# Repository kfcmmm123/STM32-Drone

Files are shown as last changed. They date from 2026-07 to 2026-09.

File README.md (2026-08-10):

# STM32 Quadcopter

A custom **STM32F103C8T6** + **FreeRTOS** quadcopter system with separate flight-controller (FC) and radio-controller (RC) boards.

The project focuses on real-time embedded firmware, attitude estimation, closed-loop flight control, wireless communication, and flight-safety logic.

## Features 

- FreeRTOS multi-task firmware architecture
- MPU6050 IMU acquisition and filtering
- Quaternion-based attitude estimation
- Cascaded angle–angular velocity PID control
- Altitude sensing and altitude-hold mode
- Si24R1 2.4 GHz wireless communication
- PWM control for four coreless motors
- Flight-state management and Safe-Unlock logic
- Connection-loss detection and failsafe motor ramp-down
- OLED and LED status feedback
- Power-management logic

--- 

## System Architecture

### Flight Controller

- **MCU:** STM32F103C8T6 + FreeRTOS
- **IMU:** MPU6050 over I²C
- **Altitude Sensor:** VL53L1X ToF sensor over I²C
- **Motors:** 4× 8520 coreless motors with timer/PWM control
- **Wireless:** Si24R1 2.4 GHz transceiver over SPI
- **Power:** Battery power management with IP5305T
- **Indicators:** GPIO-controlled status LEDs
- **Debug:** SWD interface

### Radio Controller

- **MCU:** STM32F103C8T6 + FreeRTOS
- **Input:** Dual analog joysticks through ADC
- **Controls:** GPIO push buttons
- **Display:** OLED display
- **Wireless:** Si24R1 2.4 GHz transceiver over SPI
- **Power:** IP5305T power management

---

## Hardware Design

Both controller boards were designed and routed in **EasyEDA**, with consideration for:

- Ground planes and low-noise signal return paths
- Separation of motor power and sensitive digital/sensor signals
- Short SPI and I²C routing
- High-current motor routing
- Local decoupling and power regulation
- Peripheral and timer-aware STM32 pin assignment
- Mechanical clearance and component placement

### Flight Controller PCB

The FC integrates the STM32, IMU, range sensor, RF module, motor drivers, power circuitry, and debug interfaces onto a compact PCB.

<div className="grid grid-cols-2 gap-2 my-6">
  <div>
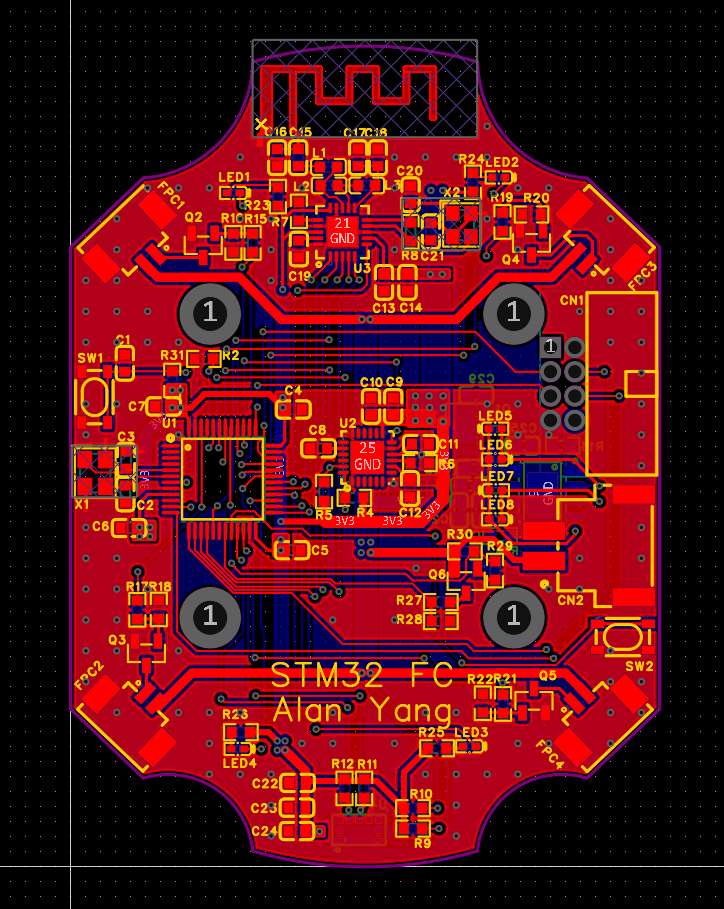
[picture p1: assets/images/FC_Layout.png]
FC Layout
    
    <p className="text-center text-sm">FC Layout</p>
  </div>
  <div>
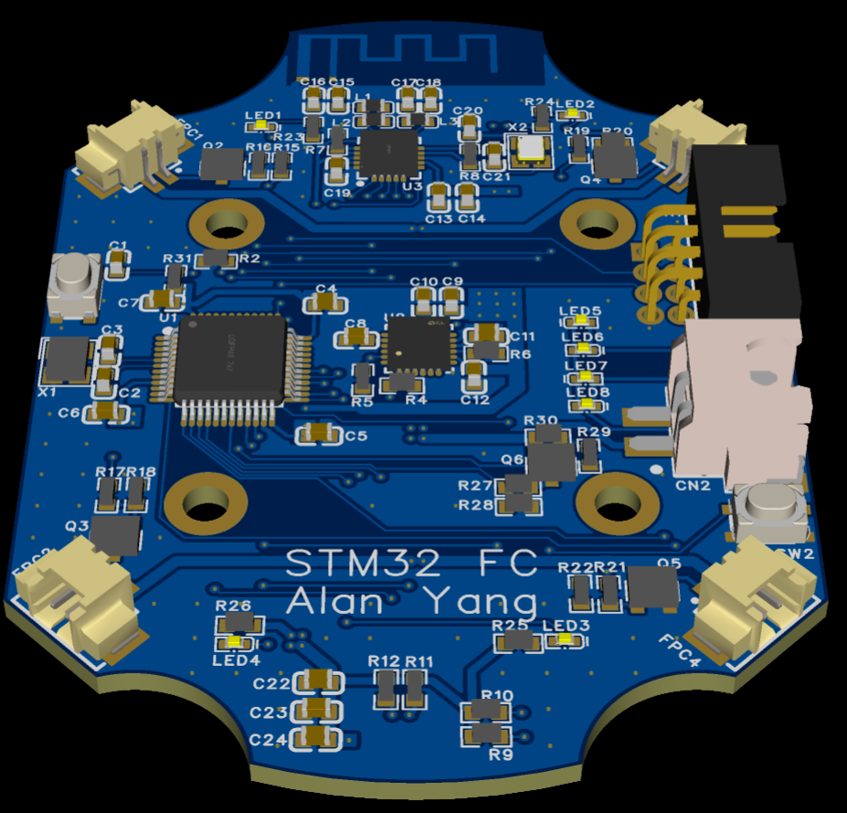
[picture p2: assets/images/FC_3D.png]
FC 3D Visualization
    
    <p className="text-center text-sm">FC 3D Visualization</p>
  </div>
</div>

### Radio Controller PCB

The RC integrates dual joysticks, control buttons, OLED feedback, RF communication, and portable power management into a handheld controller.

<div className="grid grid-cols-2 gap-2 my-6">
  <div>
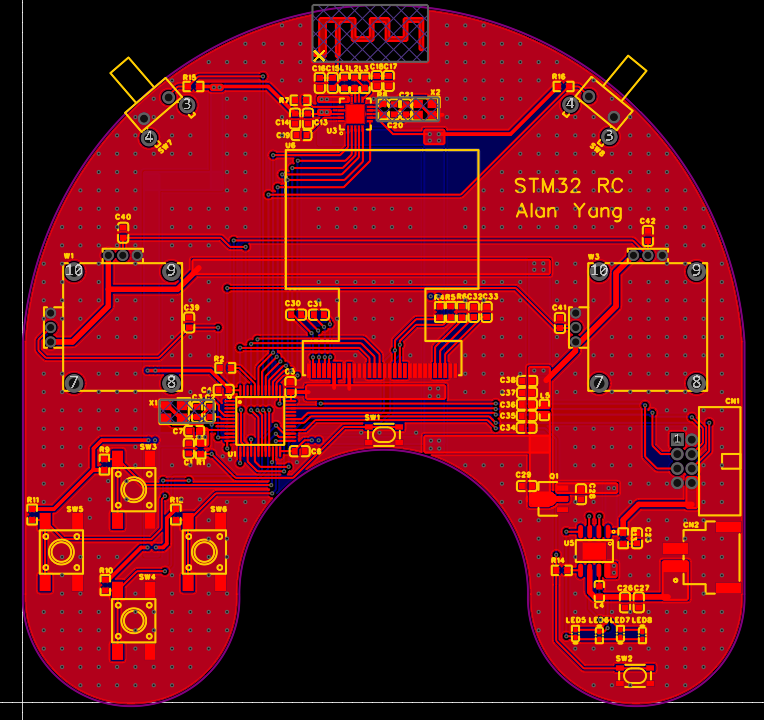
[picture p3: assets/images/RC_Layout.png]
RC Layout
    
    <p className="text-center text-sm">RC Layout</p>
  </div>
  <div>
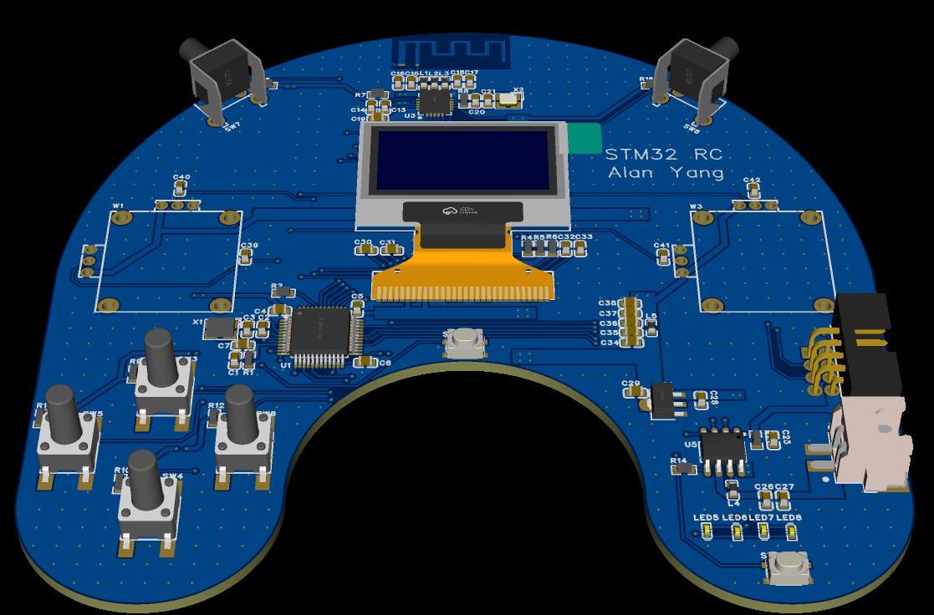
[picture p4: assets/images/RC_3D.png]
RC 3D Visualization
    
    <p className="text-center text-sm">RC 3D Visualization</p>
  </div>
</div>

### Assembled PCBs

<div className="grid grid-cols-2 gap-2 my-6">
  <div>
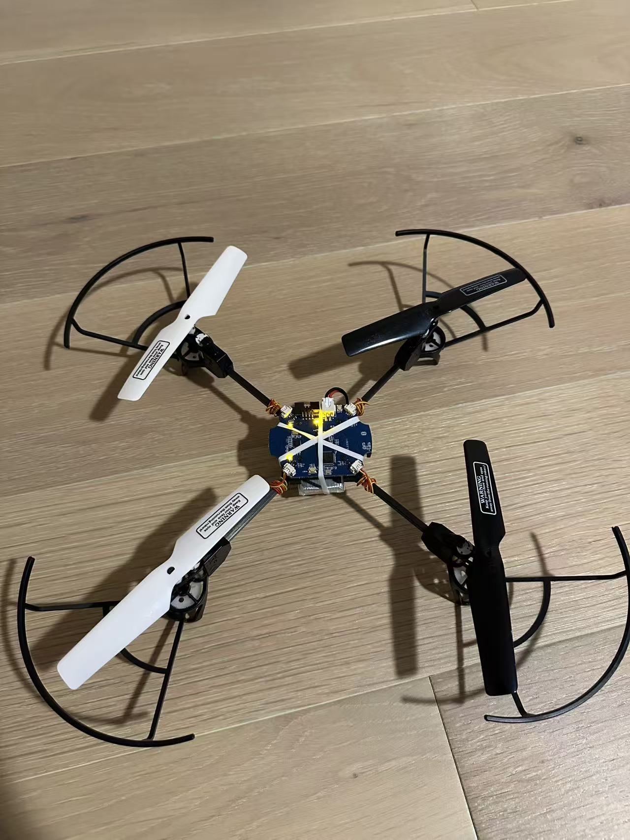
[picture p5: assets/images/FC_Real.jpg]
FC PCB
    
    <p className="text-center text-sm">FC PCB</p>
  </div>
  <div>
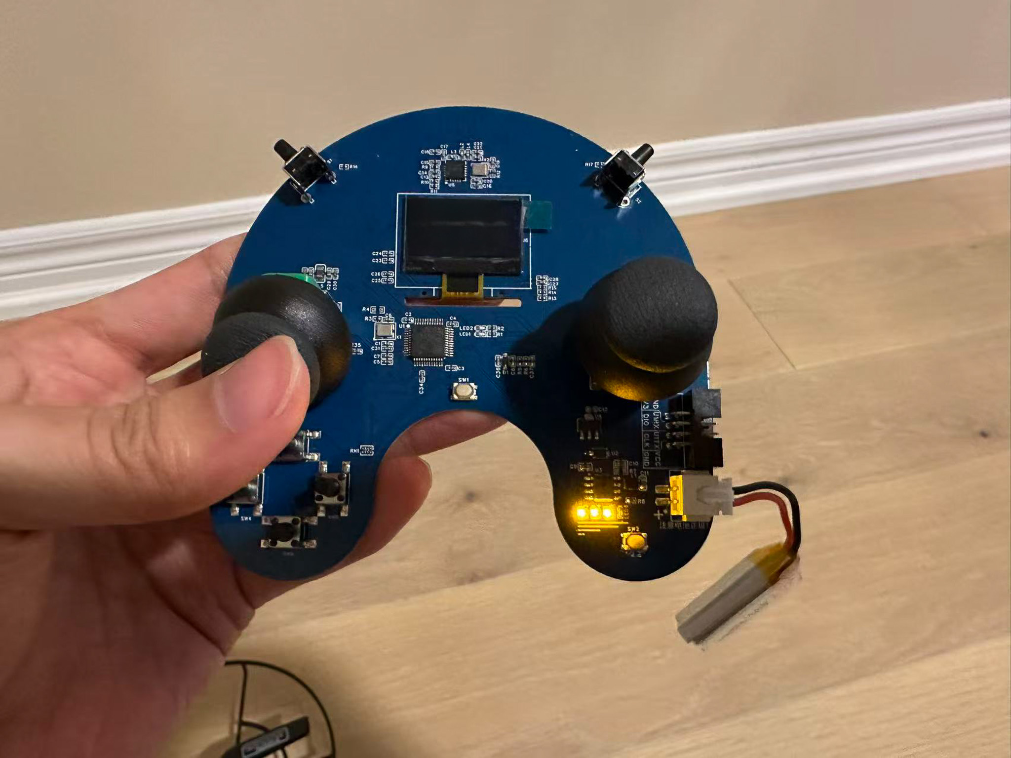
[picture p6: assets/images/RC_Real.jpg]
RC PCB
    
    <p className="text-center text-sm">RC PCB</p>
  </div>
</div>

---

## Firmware Development

The firmware is built on **FreeRTOS** with a layered architecture separating application, control algorithm, and hardware driver logic.

### Key Features

- FreeRTOS multi-task architecture
- Quaternion-based attitude estimation with sensor filtering
- Cascaded angle–angular velocity PID flight control
- Altitude-hold control using VL53L1X
- Custom Si24R1 2.4 GHz communication protocol
- Safe-Unlock, flight state machine, and Failsafe protection

### Flight Controller (FC)

- Reads and filters MPU6050 IMU data for real-time attitude estimation
- Runs cascaded PID control and mixes outputs across four motors
- Supports altitude hold and `IDLE`, `NORMAL`, `FIX_HEIGHT`, and `FAULT` states
- Handles wireless loss, Failsafe, Safe-Unlock, and shutdown behavior

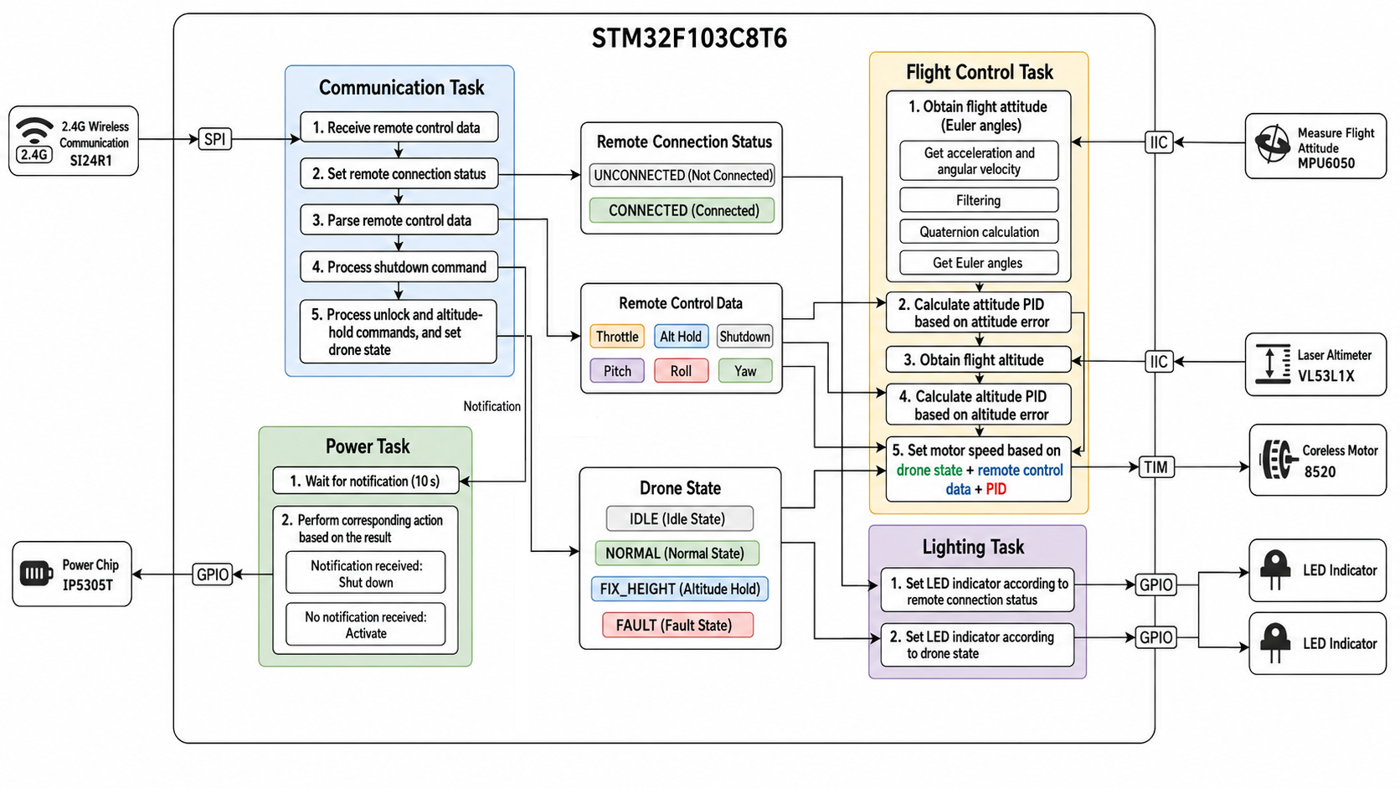
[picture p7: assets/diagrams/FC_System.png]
FC FW System


### Radio Controller (RC)

- Samples and calibrates dual analog joysticks through ADC
- Generates throttle, pitch, roll, yaw, altitude-hold, and system commands
- Packages and transmits validated control packets over Si24R1
- Manages OLED feedback, buttons, connection status, and power

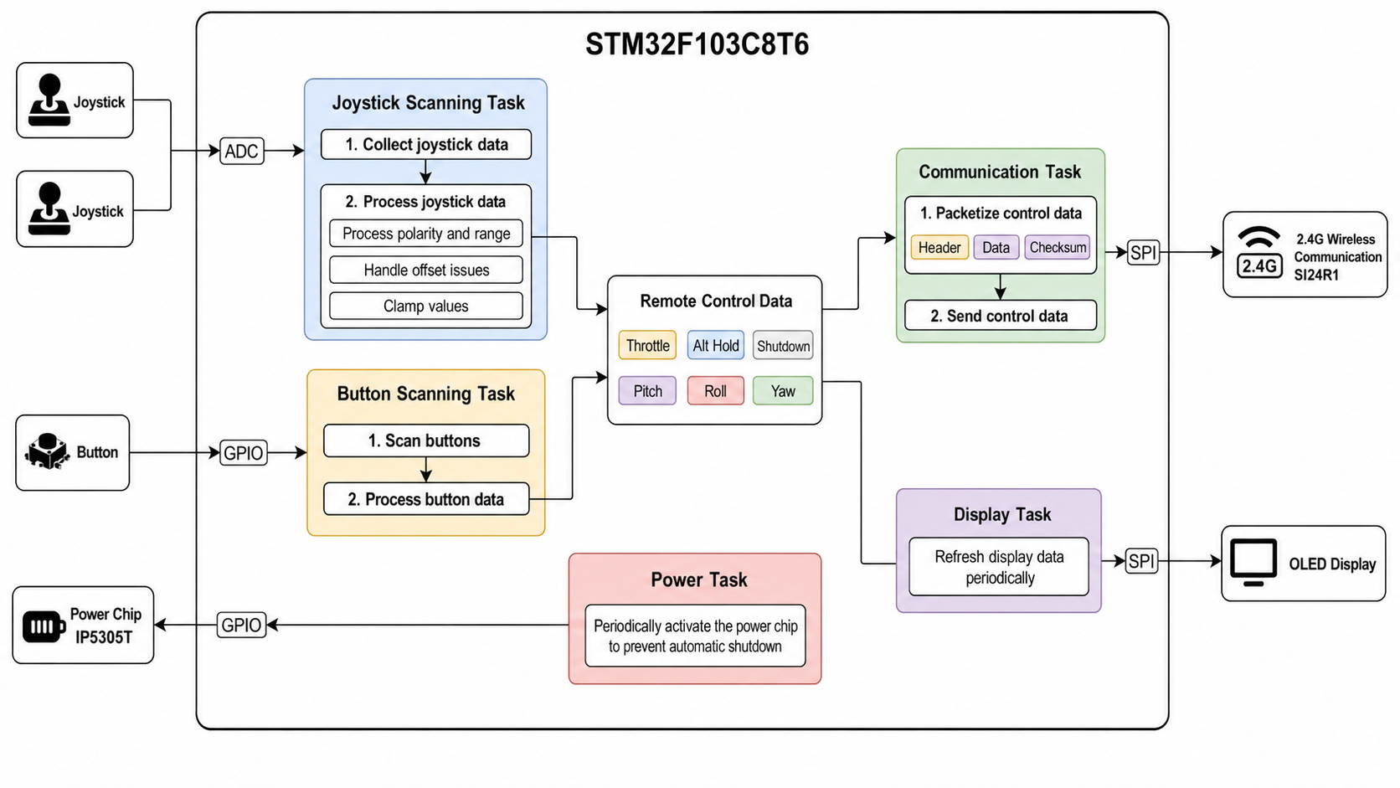
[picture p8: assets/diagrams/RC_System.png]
FC FW System


---

## Skills Demonstrated

- STM32 embedded C & FreeRTOS development
- Schematic design & PCB layout
- SPI, I²C, ADC, GPIO & PWM
- IMU filtering & quaternion attitude estimation
- Cascaded PID flight control
- Embedded state machines & Failsafe design
- Custom 2.4 GHz wireless communication
- Hardware/firmware system integration

This project demonstrates the complete embedded systems workflow: from PCB design and hardware integration to real-time firmware, wireless communication, sensor processing, and closed-loop flight control.

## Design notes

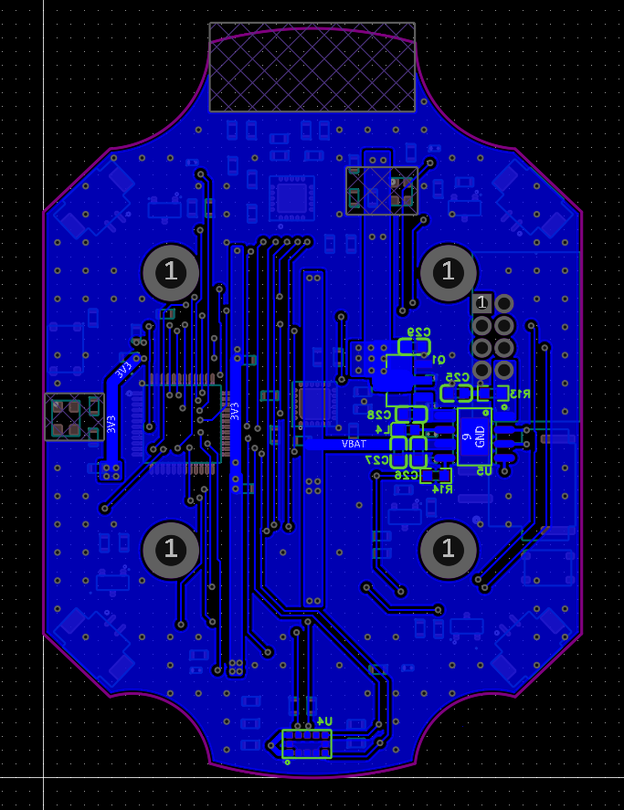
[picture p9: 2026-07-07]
assets/images/FC_Bot.png

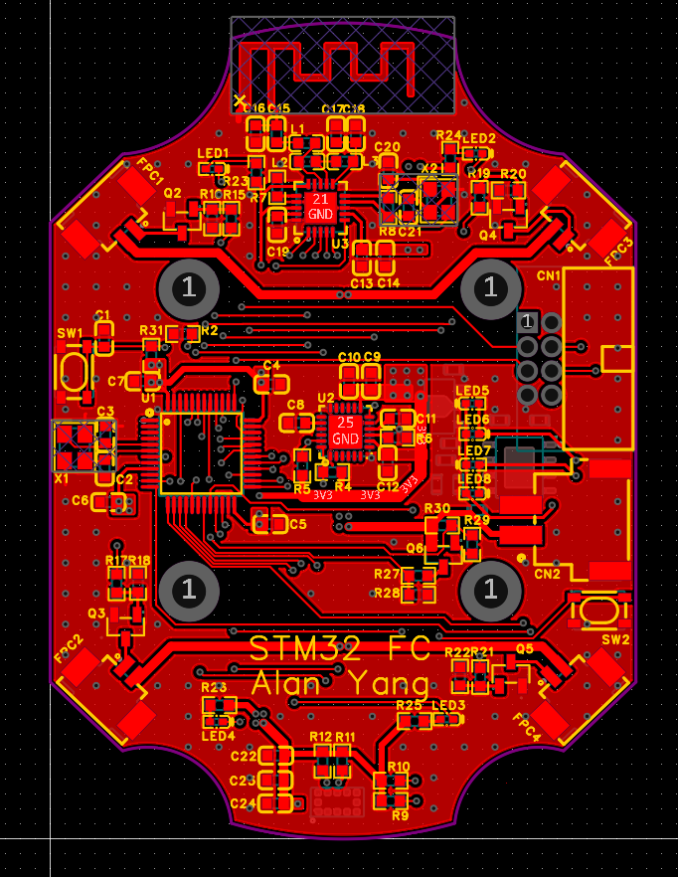
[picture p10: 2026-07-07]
assets/images/FC_Top.png

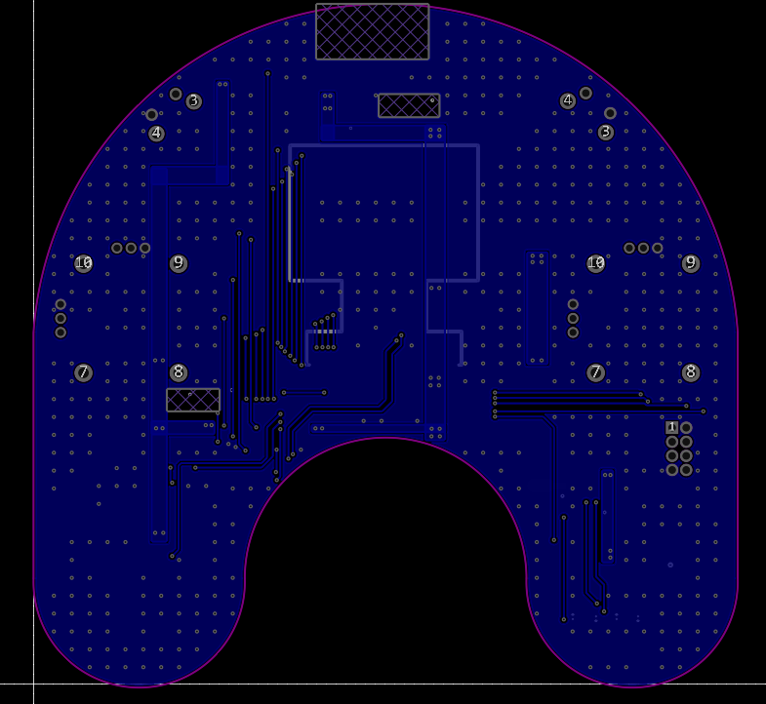
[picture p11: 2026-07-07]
assets/images/RC_Bot.png

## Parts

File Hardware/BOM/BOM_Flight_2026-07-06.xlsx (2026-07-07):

No. | Quantity | Comment | Designator | Footprint | Value | Manufacturer Part | Manufacturer | Supplier Part | Supplier
1 | 9 | 100nF | C1,C4,C5,C6,C7,C9,C11,C13,C22 | C0603 | 100nF
2 | 2 | 12pF | C2,C3 | C0603 | 12pF
3 | 2 | 10nF | C8,C12 | C0603 | 10nF
4 | 2 | 2.2nF | C10,C18 | C0603 | 2.2nF
5 | 5 | 10uF | C14,C26,C27,C28,C29 | C0603 | 10uF
6 | 1 | 1.5pF | C15 | C0603 | 1.5pF
7 | 2 | 1pF | C16,C24 | C0603 | 1pF
8 | 1 | 4.7pF | C17 | C0603 | 4.7pF
9 | 1 | 33nF | C19 | C0603 | 33nF
10 | 2 | 22pF | C20,C21 | C0603 | 22pF
11 | 1 | 4.7uF | C23 | C0603 | 4.7uF
12 | 1 | 2.2uF | C25 | C0603 | 2.2uF
13 | 1 | 3111-08RG0BK00T1 | CN1 | CONN-TH_3111-08RG0BK00T1 |  | 3111-08RG0BK00T1 | Wcon(维峰电子) | C720751 | LCSC
14 | 1 | ZX-XH2.54-2PWT | CN2 | CONN-SMD_2P-P2.54_MEGASTAR_ZX-XH2.54-2PWT |  | ZX-XH2.54-2PWT | Megastar(兆星) | C7429671 | LCSC
15 | 4 | 1.25-2PWB | FPC1,FPC2,FPC3,FPC4 | CONN-SMD_2P-P1.25_DEALON_1.25-2PWB |  | 1.25-2PWB | DEALON(德艺隆) | C2905009 | LCSC
16 | 1 | 3.9uH | L1 | L0603 | 3.9uH
17 | 1 | 8.2nH | L2 | L0603 | 8.2nH
18 | 1 | 2.7nH | L3 | L0603 | 2.7nH
19 | 1 | 1.5uH | L4 | L0603 | 1.5uH
20 | 8 | XL-1005UYC | LED1,LED2,LED3,LED4,LED5,LED6,LED7,LED8 | LED0402-FD_YELLOW |  | XL-1005UYC | XINGLIGHT(成兴光) | C25503856 | LCSC
21 | 1 | AMS1117-3.3V | Q1 | SOT-89-3_L4.5-W2.5-P1.50-LS4.2-BR |  | AMS1117-3.3V | MSKSEMI(美森科) | C5120796 | LCSC
22 | 4 | AO3400A | Q2,Q3,Q4,Q5 | SOT-23-3_L2.9-W1.3-P1.90-LS2.4-BR |  | AO3400A | UMW(友台半导体) | C347475 | LCSC
23 | 1 | SI2301A | Q6 | SOT-23-3_L2.9-W1.3-P1.90-LS2.4-BR |  | SI2301A | UMW(友台半导体) | C347482 | LCSC
24 | 16 | 10K | R2,R6,R9,R10,R11,R12,R14,R16,R18,R20,R22,R23,R24,R25,R26,R31 | R0603 | 10K
25 | 2 | 10KΩ | R4,R5 | R0603 | 10KΩ
26 | 1 | 22K | R7 | R0603 | 22K
27 | 1 | 1MΩ | R8 | R0603 | 1MΩ
28 | 1 | 1.5Ω | R13 | R0603 | 1.5Ω
29 | 5 | 1K | R15,R17,R19,R21,R29 | R0603 | 1K
30 | 3 | 100K | R27,R28,R30 | R0603 | 100K
31 | 2 | SKRPACE010 | SW1,SW2 | KEY-SMD_4P-L4.2-W3.2-P2.20-LS4.6 |  | SKRPACE010 | ALPSALPINE(阿尔卑斯阿尔派) | C139797 | LCSC
32 | 1 | STM32F103C8T6 | U1 | LQFP-48_L7.0-W7.0-P0.50-LS9.0-BL |  | STM32F103C8T6 | ST(意法半导体) | C8734 | LCSC
33 | 1 | MPU-6050 | U2 | QFN-24_L4.0-W4.0-P0.50-BL-EP2.7 |  | MPU-6050 | TDK InvenSense(应美盛) | C24112 | LCSC
34 | 1 | Si24R1 | U3 | QFN-20_L4.0-W4.0-P0.50-BL-EP |  | Si24R1 | 南京中科微 | C14436 | LCSC
35 | 1 | VL53L4CDV0DH/1 | U4 | LGA-12_L4.4-W2.4_VL53L0X |  | VL53L4CDV0DH/1 | ST(意法半导体) | C3178291 | LCSC
36 | 1 | TP4336 | U5 | ESOP-8_L4.9-W3.9-P1.27-LS6.0-BL-EP-1 |  | TP4336 | TPOWER(天源) | C29075510 | LCSC
37 | 1 | 8MHz | X1 | CRYSTAL-SMD_4P-L3.2-W2.5-BL | 8MHz | TAXM8M4RLBDDT2T | YJX(雅晶鑫) | C720915 | LCSC
38 | 1 | - | X2 | CRYSTAL-SMD_4P-L2.5-W2.0-BL-2 | - | SX25Y016000B91T | TKD(泰晶) | C271644 | LCSC

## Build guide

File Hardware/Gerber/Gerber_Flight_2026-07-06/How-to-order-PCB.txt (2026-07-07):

How to Order PCB

Please refer to:
https://prodocs.easyeda.com/en/pcb/order-order-pcb/index.html

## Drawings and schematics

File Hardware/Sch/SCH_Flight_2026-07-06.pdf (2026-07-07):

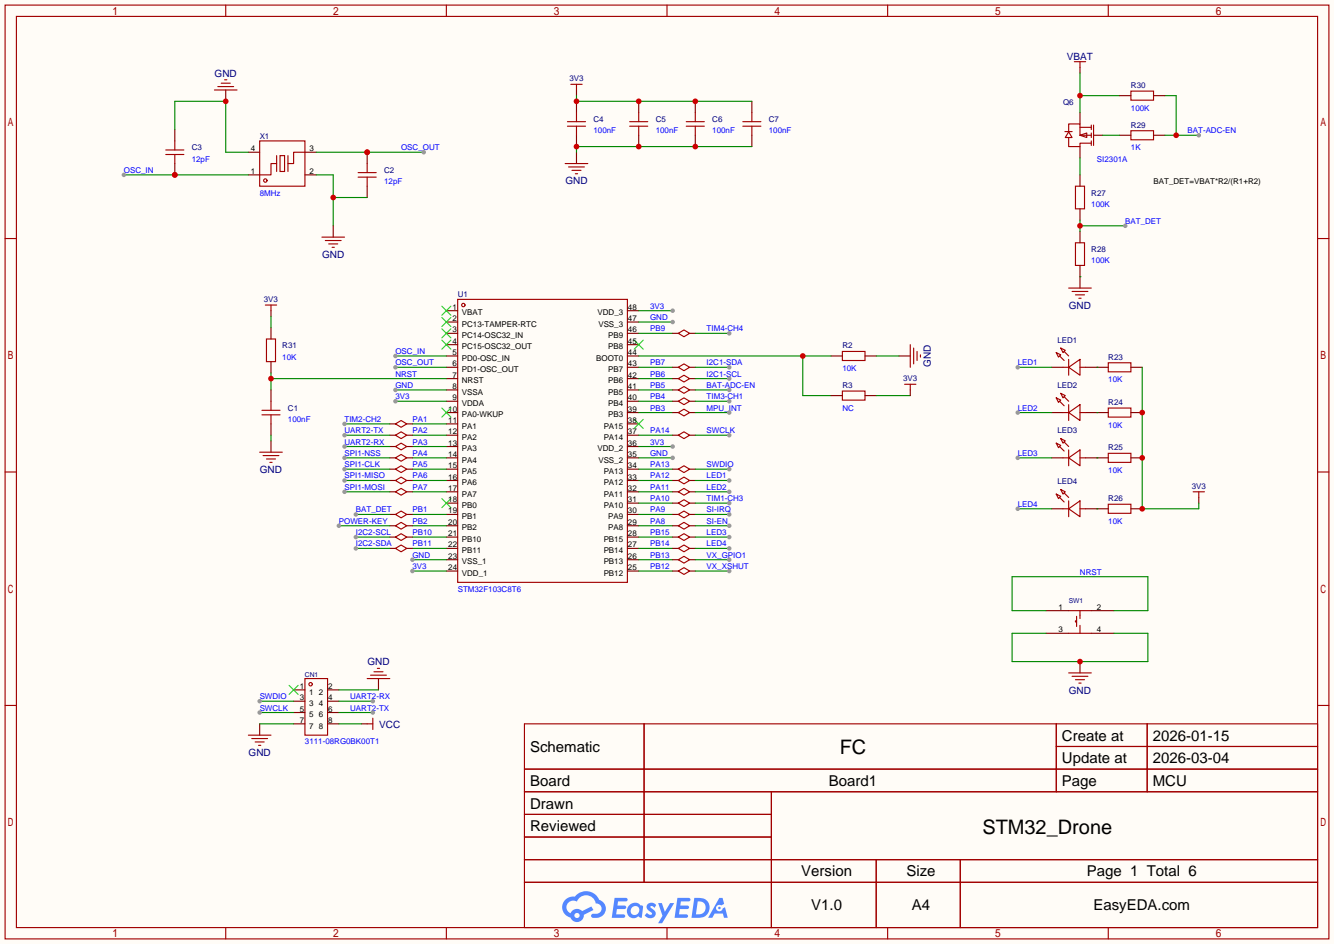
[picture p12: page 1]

Schematic | FC | Create at | 2026-01-15

Update at | 2026-03-04

Board | Board1 | Page | MCU
Drawn | | STM32_Drone
Reviewed

Version | Size | Page 1 Total 6
V1.0 | A4 | EasyEDA.com

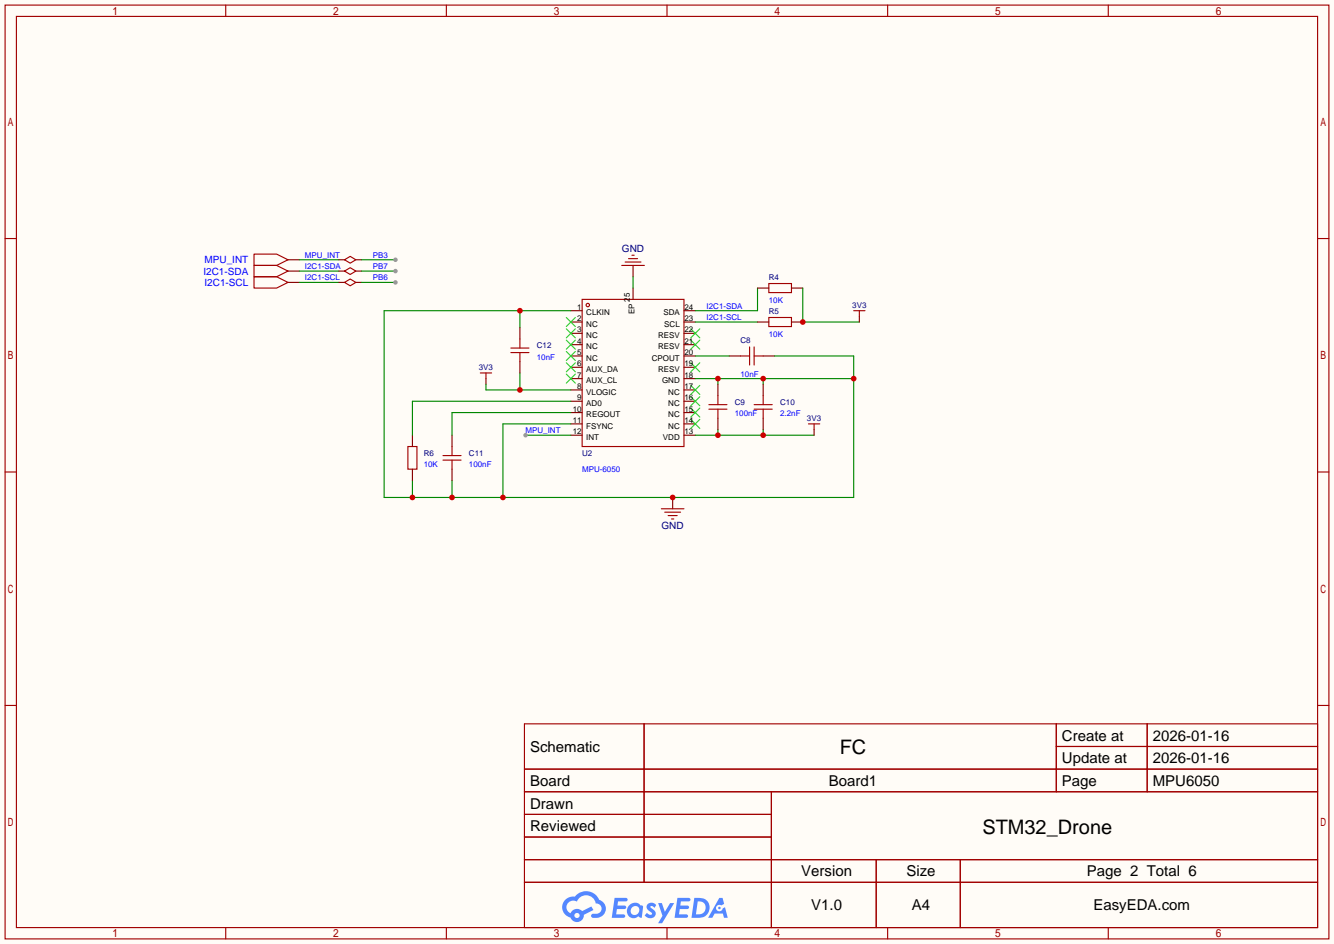
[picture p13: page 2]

Schematic | FC | Create at | 2026-01-16

Update at | 2026-01-16

Board | Board1 | Page | MPU6050
Drawn | | STM32_Drone
Reviewed

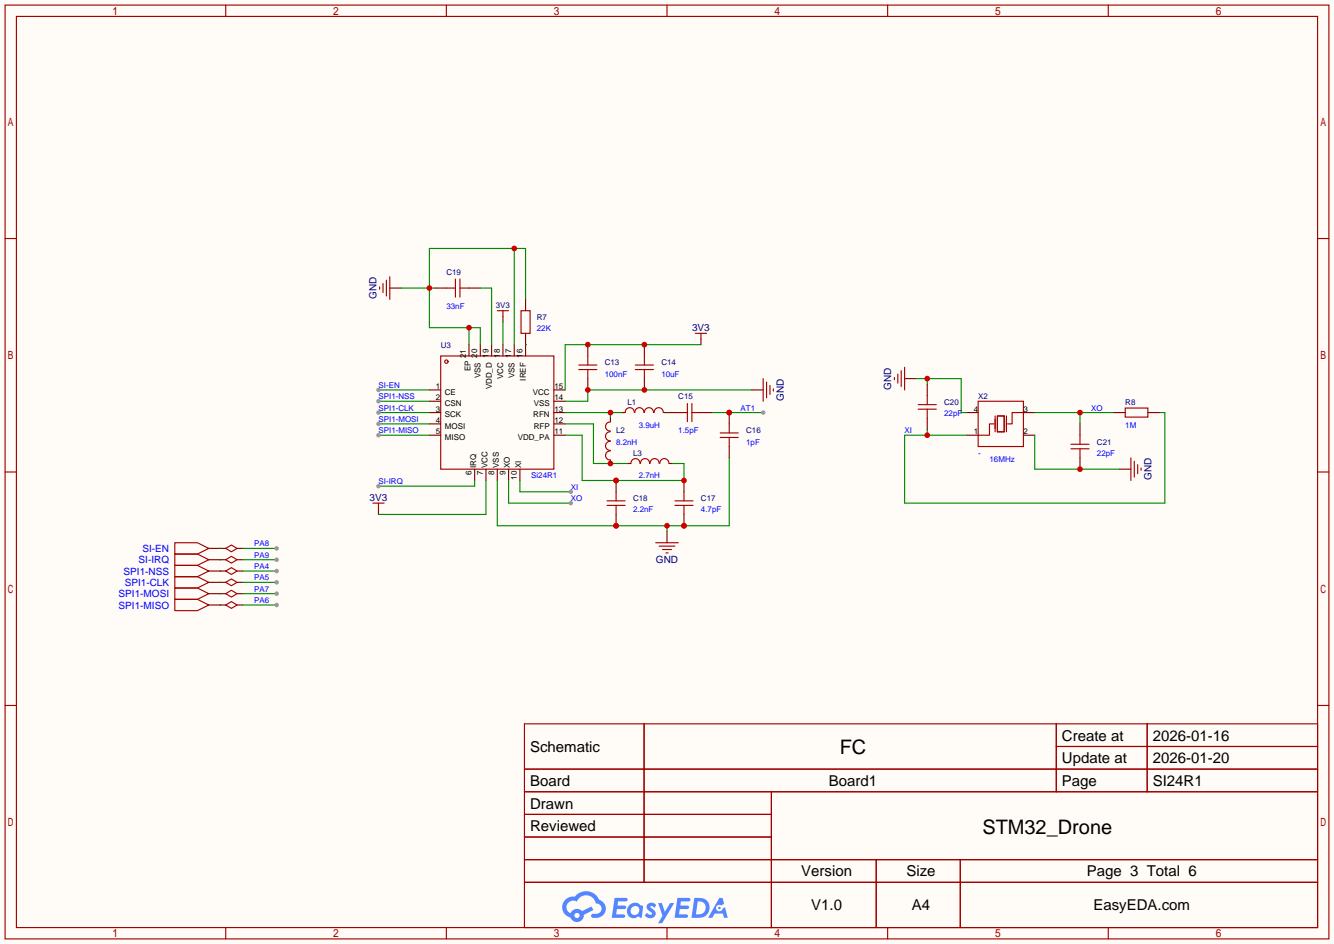
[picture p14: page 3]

Schematic | FC | Create at | 2026-01-16

Update at | 2026-01-20

Board | Board1 | Page | SI24R1
Drawn | | STM32_Drone
Reviewed

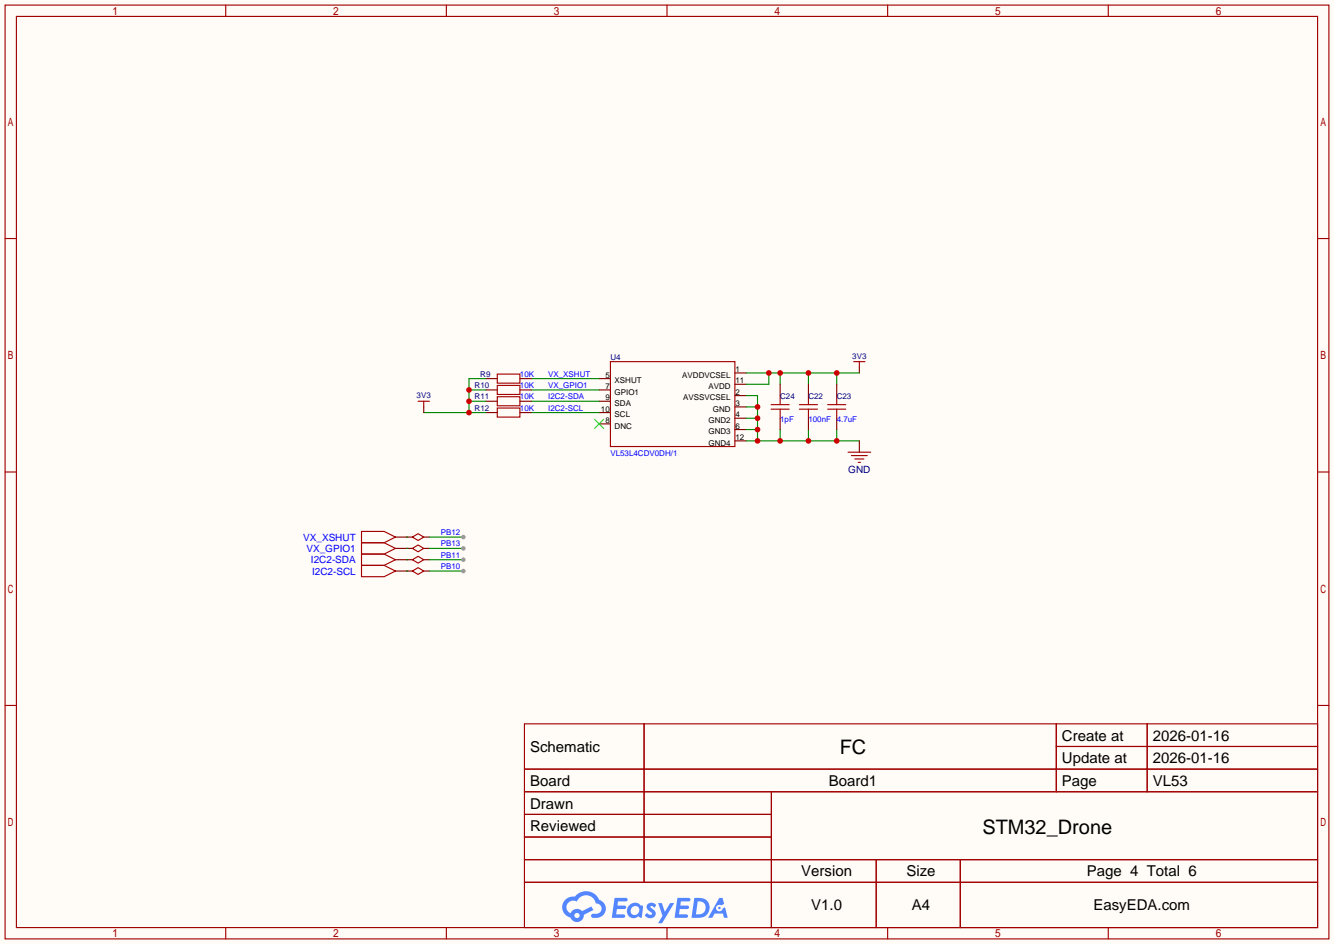
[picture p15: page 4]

Schematic | FC | Create at | 2026-01-16

Update at | 2026-01-16

Board | Board1 | Page | VL53
Drawn | | STM32_Drone
Reviewed

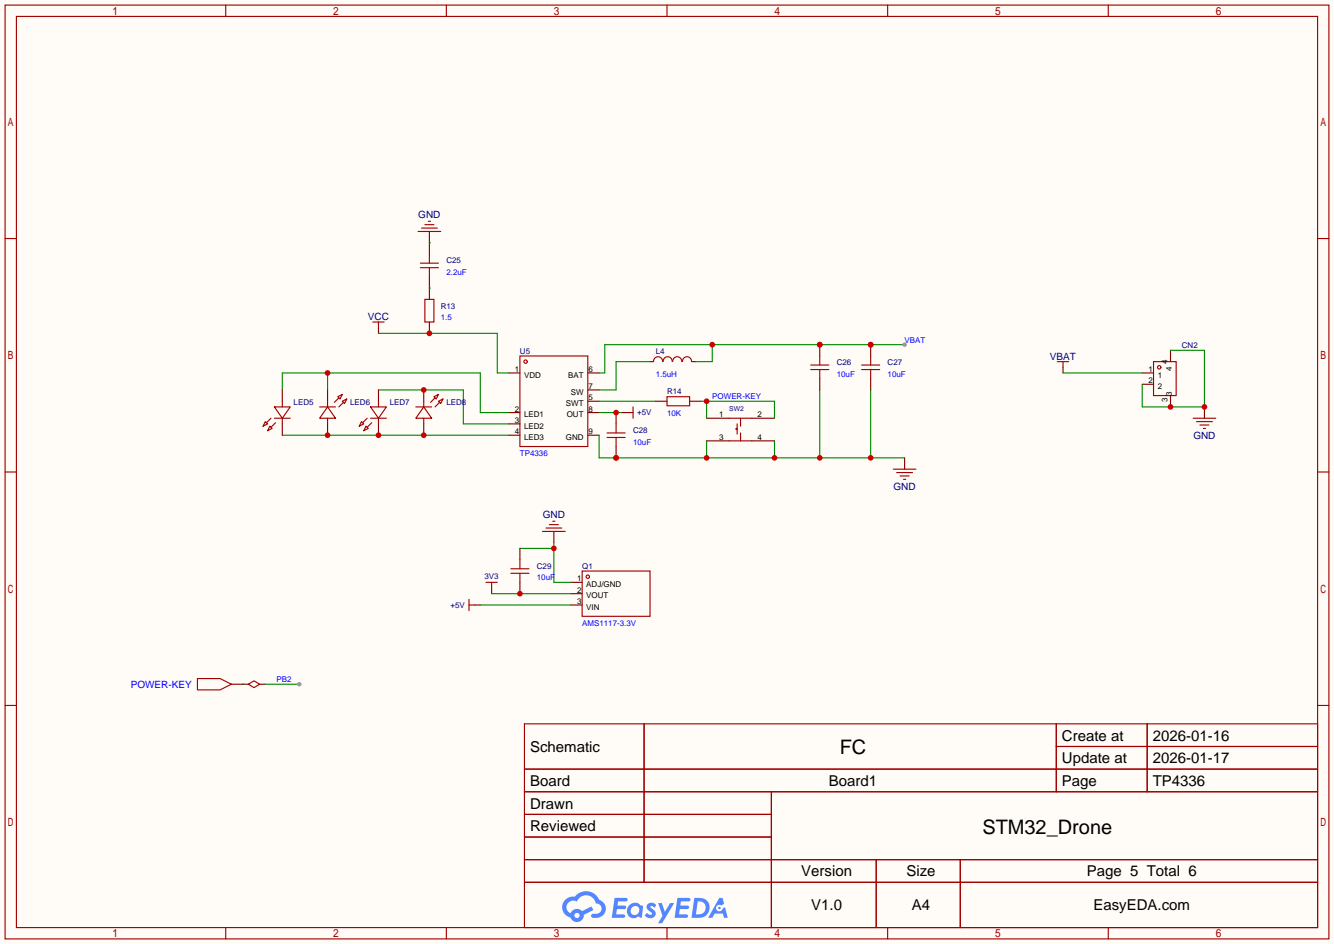
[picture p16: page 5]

Schematic | FC | Create at | 2026-01-16

Update at | 2026-01-17

Board | Board1 | Page | TP4336
Drawn | | STM32_Drone
Reviewed

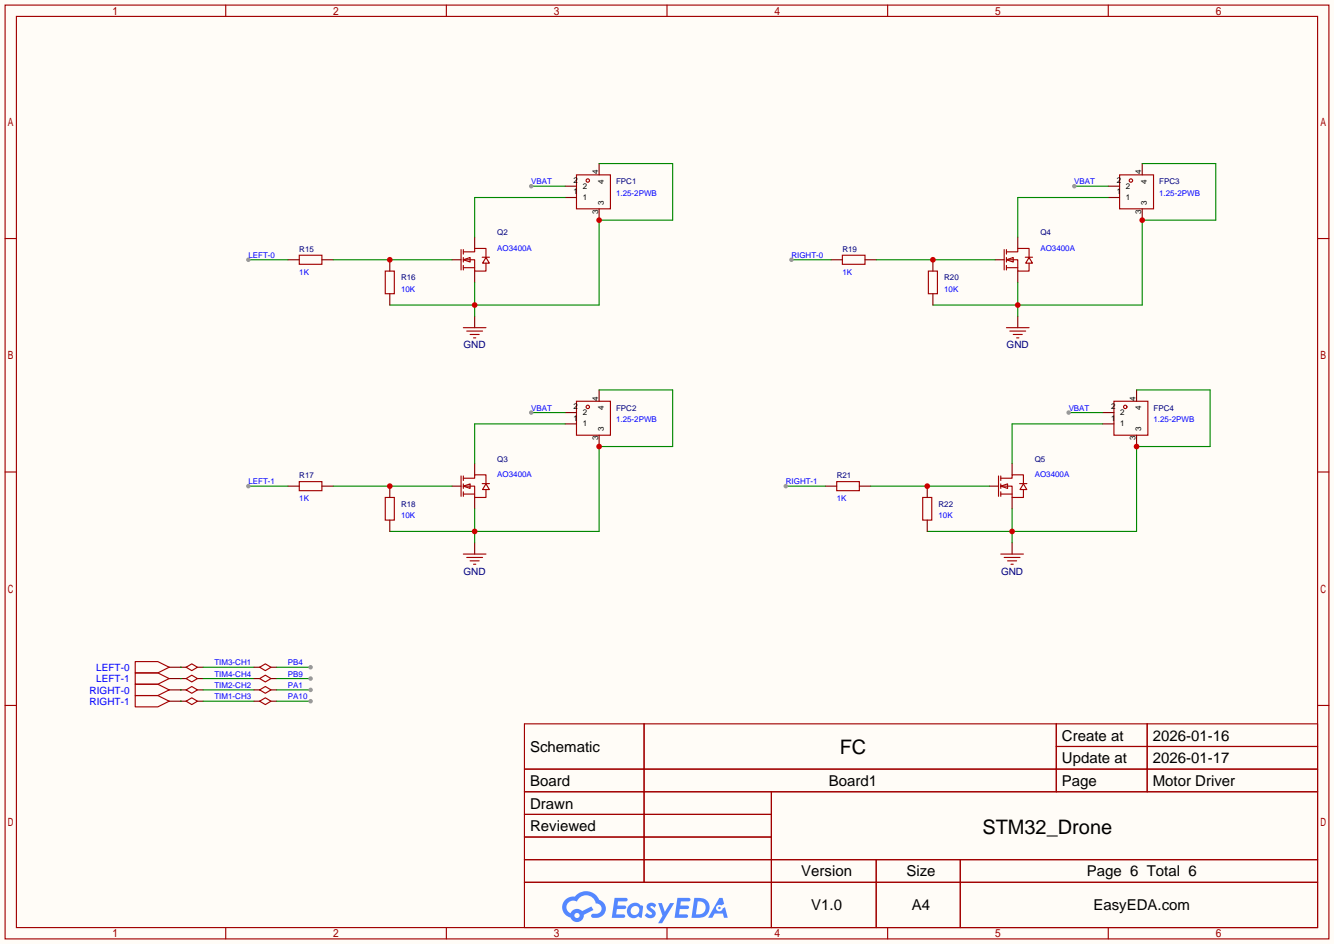
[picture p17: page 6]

Schematic | FC | Create at | 2026-01-16

Update at | 2026-01-17

Board | Board1 | Page | Motor Driver
Drawn | | STM32_Drone
Reviewed

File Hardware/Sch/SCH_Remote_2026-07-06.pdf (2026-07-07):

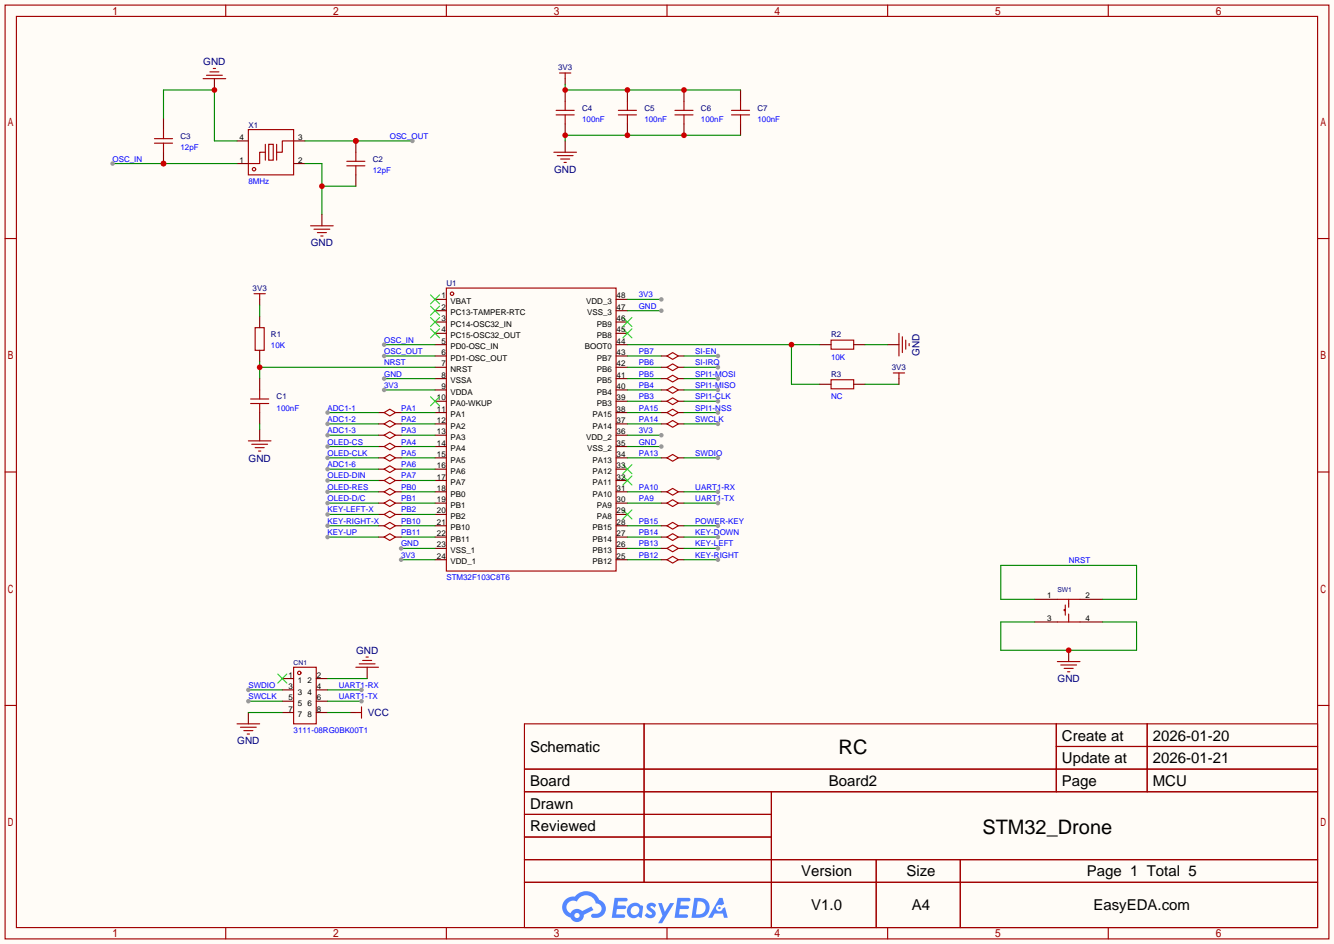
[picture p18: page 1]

Schematic | RC | Create at | 2026-01-20

Update at | 2026-01-21

Board | Board2 | Page | MCU
Drawn | | STM32_Drone
Reviewed

Version | Size | Page 1 Total 5
V1.0 | A4 | EasyEDA.com

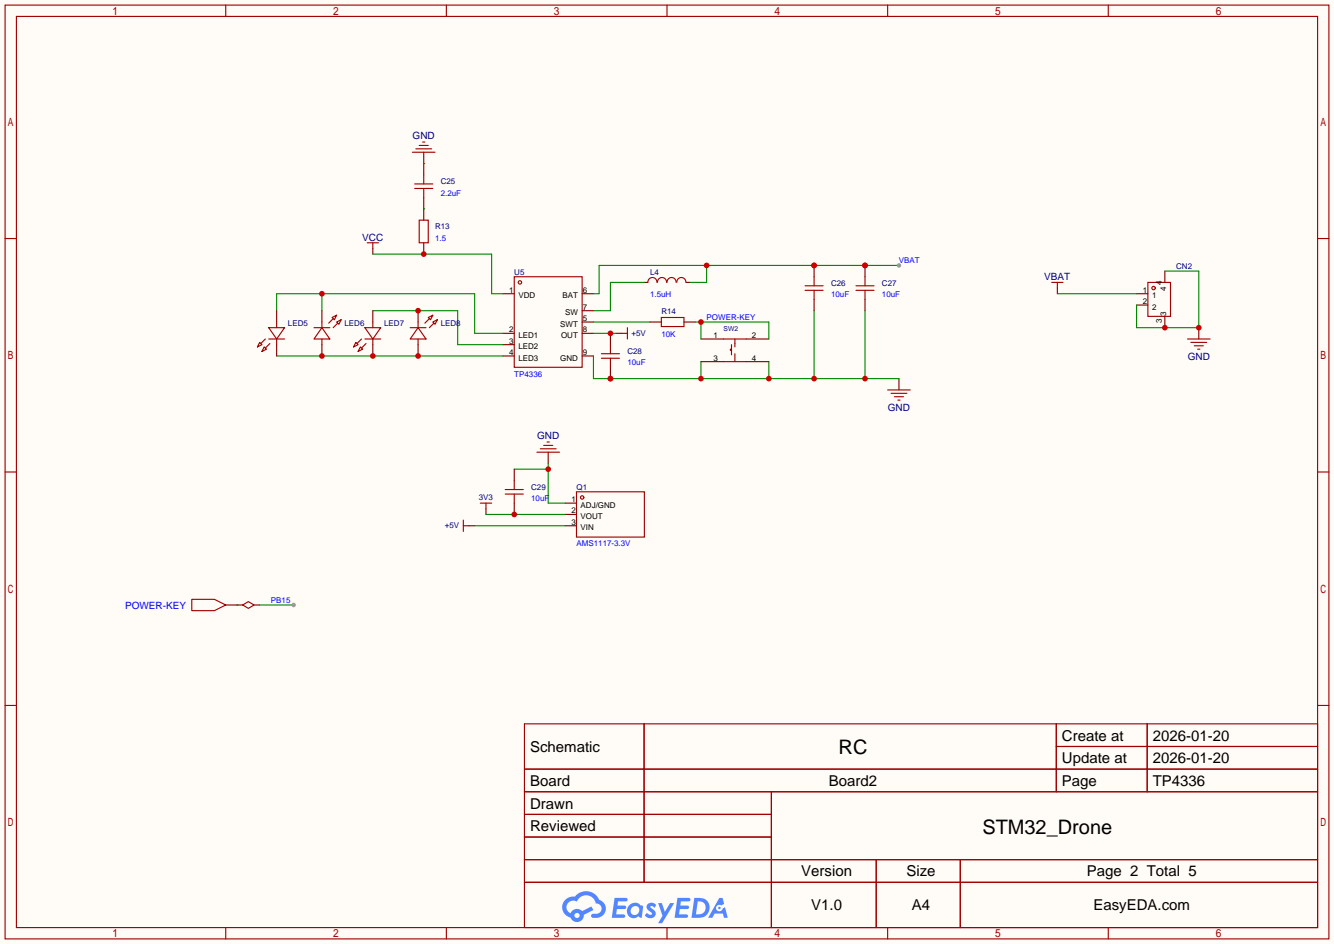
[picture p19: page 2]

Schematic | RC | Create at | 2026-01-20

Update at | 2026-01-20

Board | Board2 | Page | TP4336
Drawn | | STM32_Drone
Reviewed

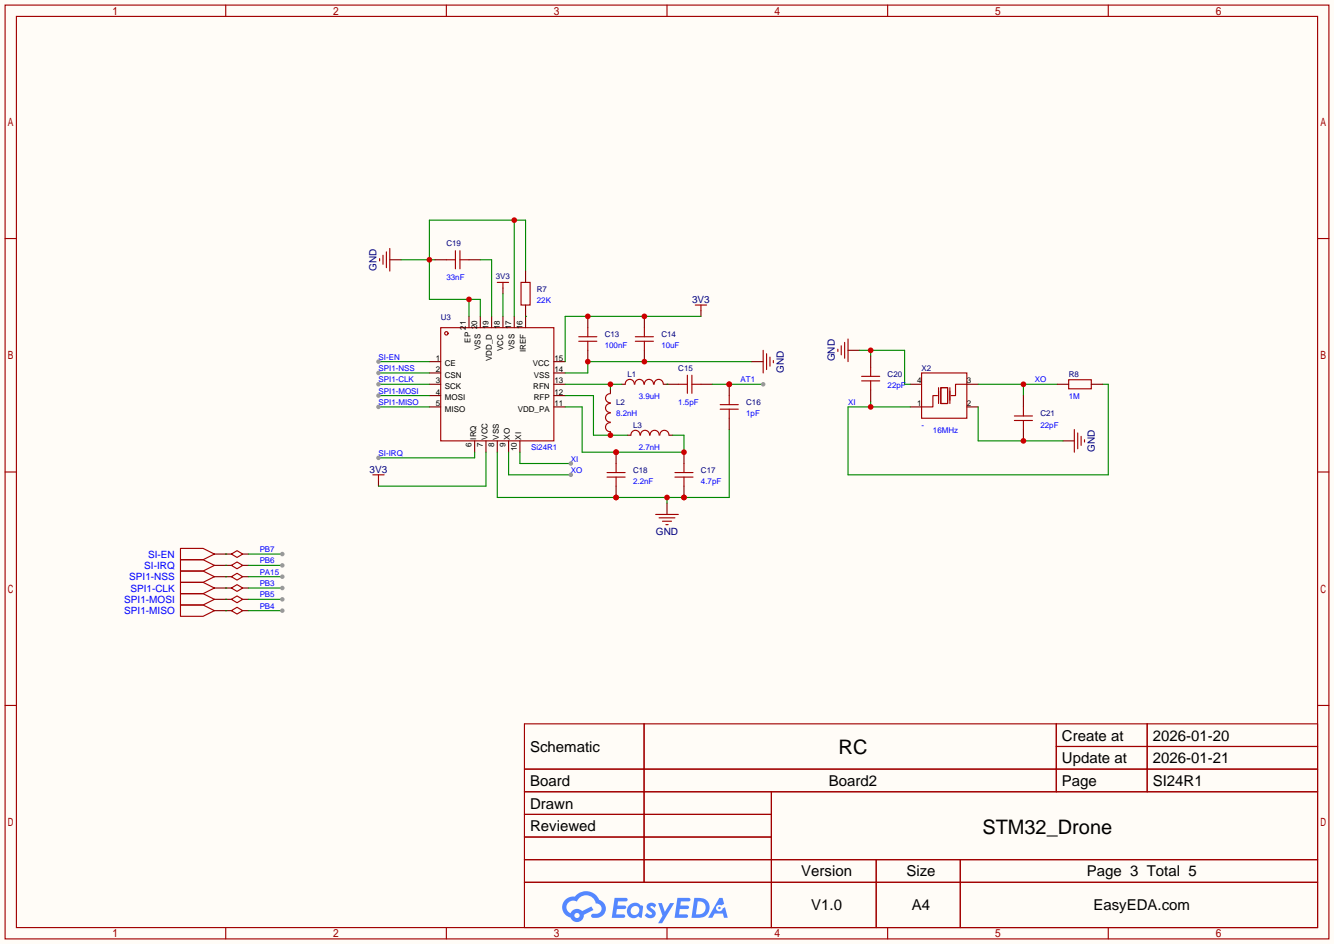
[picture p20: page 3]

Schematic | RC | Create at | 2026-01-20

Update at | 2026-01-21

Board | Board2 | Page | SI24R1
Drawn | | STM32_Drone
Reviewed

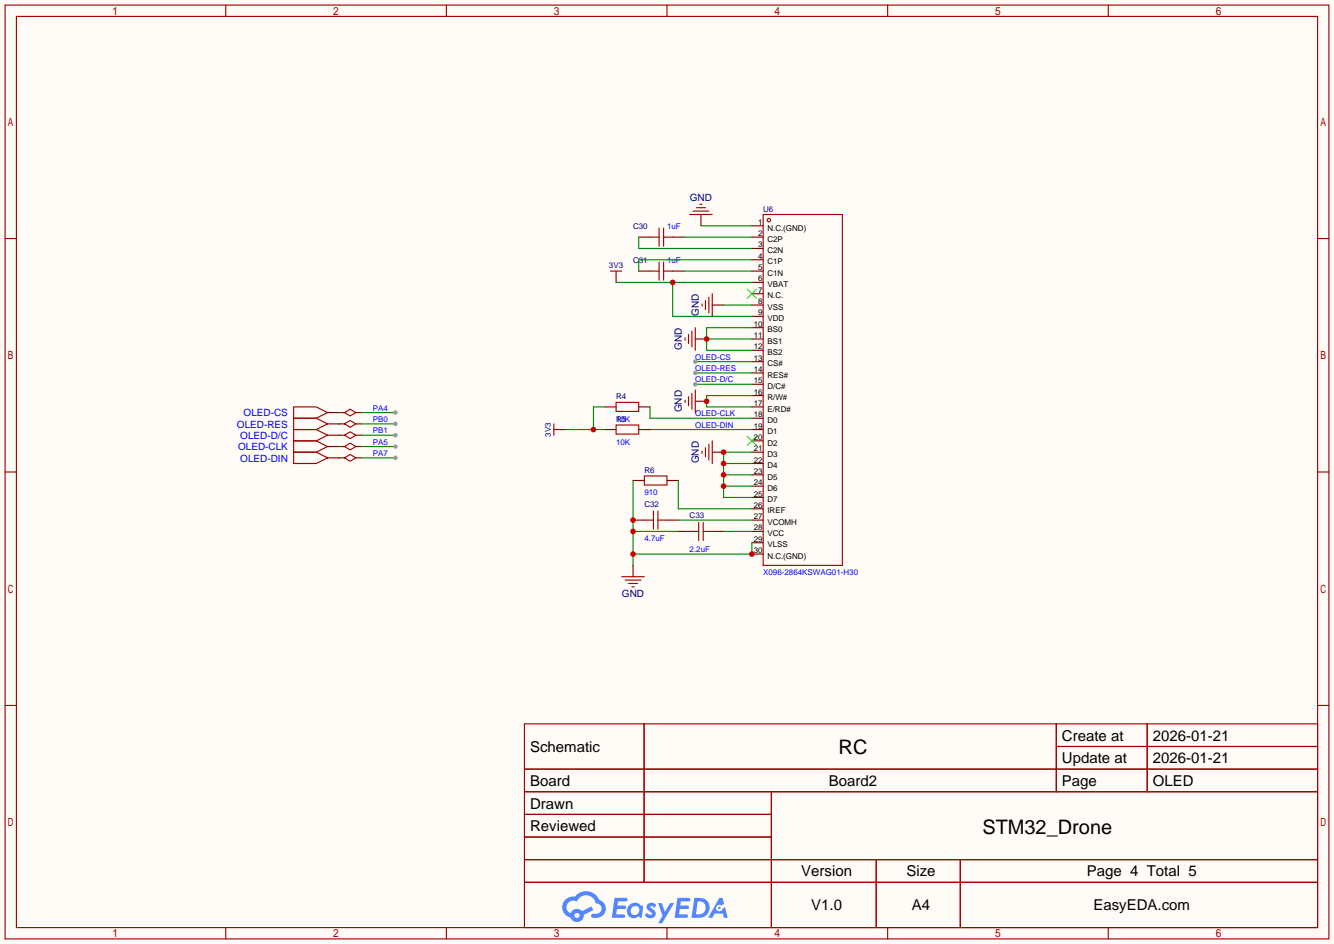
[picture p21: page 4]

Schematic | RC | Create at | 2026-01-21

Update at | 2026-01-21

Board | Board2 | Page | OLED
Drawn | | STM32_Drone
Reviewed

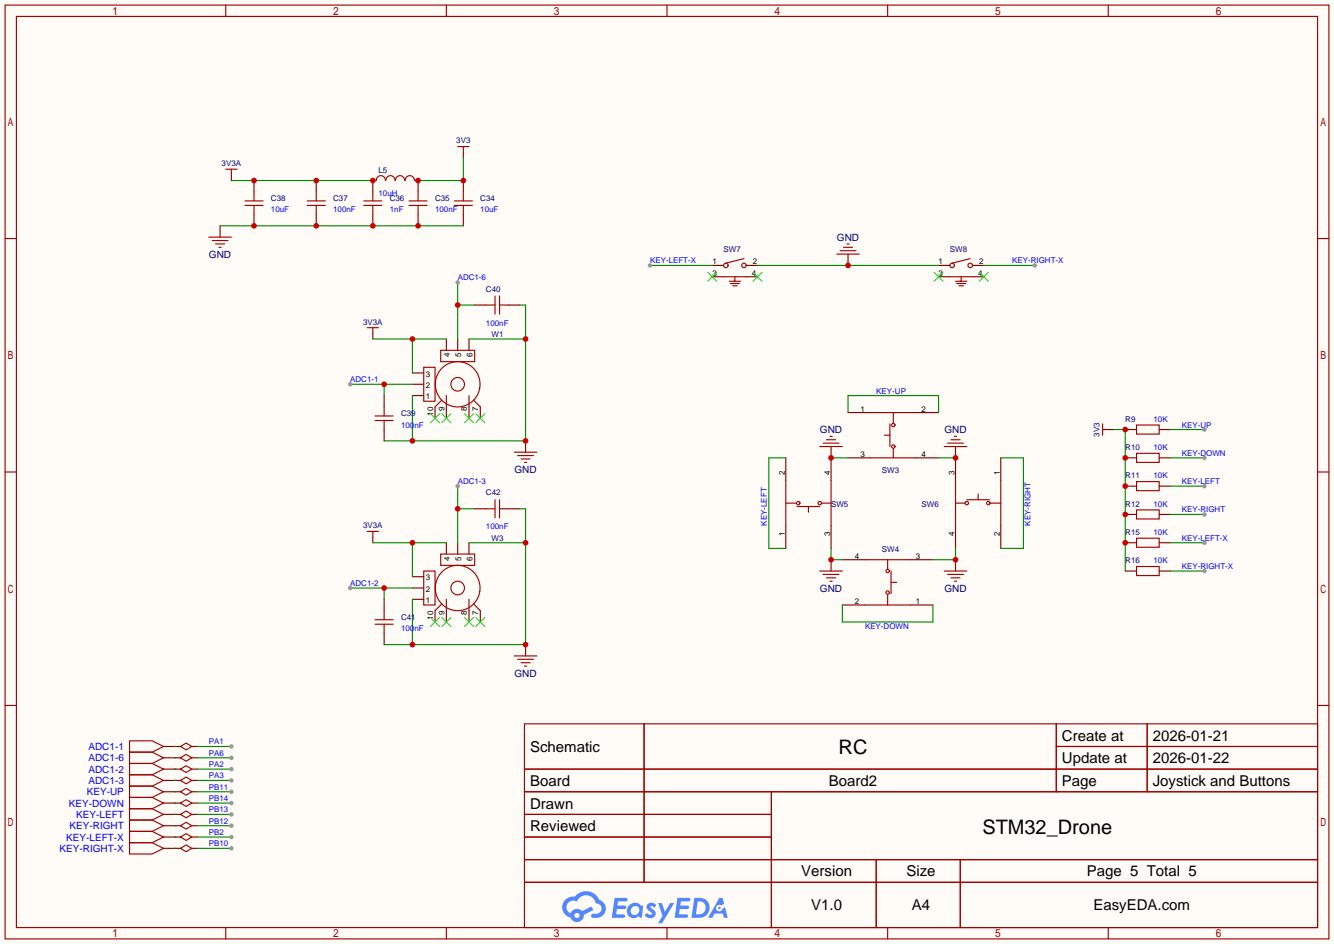
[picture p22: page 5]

Schematic | RC | Create at | 2026-01-21

Update at | 2026-01-22

Board | Board2 | Page | Joystick and Buttons
Drawn | | STM32_Drone
Reviewed

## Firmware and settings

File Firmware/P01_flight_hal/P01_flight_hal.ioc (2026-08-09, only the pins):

Mcu.UserName=STM32F103C8Tx
PA1.Signal=S_TIM2_CH2
PA10.Signal=S_TIM1_CH3
PA11.GPIO_Label=LED2
PA11.Signal=GPIO_Output
PA12.GPIO_Label=LED1
PA12.Signal=GPIO_Output
PA13.Signal=SYS_JTMS-SWDIO
PA14.Signal=SYS_JTCK-SWCLK
PA2.Signal=USART2_TX
PA3.Signal=USART2_RX
PA4.GPIO_Label=SPI1_NSS
PA4.Signal=GPIO_Output
PA5.Signal=SPI1_SCK
PA6.Signal=SPI1_MISO
PA7.Signal=SPI1_MOSI
PA8.GPIO_Label=SI_EN
PA8.Signal=GPIO_Output
PB1.Signal=ADCx_IN9
PB10.Signal=I2C2_SCL
PB11.Signal=I2C2_SDA
PB12.GPIO_Label=VX_XSHUT
PB12.Signal=GPIO_Output
PB14.GPIO_Label=LED4
PB14.Signal=GPIO_Output
PB15.GPIO_Label=LED3
PB15.Signal=GPIO_Output
PB2.GPIO_Label=POWER_KEY
PB2.Signal=GPIO_Output
PB4.Signal=S_TIM3_CH1
PB5.GPIO_Label=BAT_ADC_EN
PB5.Signal=GPIO_Output
PB6.Signal=I2C1_SCL
PB7.Signal=I2C1_SDA
PB9.Signal=S_TIM4_CH4
PC14-OSC32_IN.Signal=RCC_OSC32_IN
PC15-OSC32_OUT.Signal=RCC_OSC32_OUT
PD0-OSC_IN.Signal=RCC_OSC_IN
PD1-OSC_OUT.Signal=RCC_OSC_OUT

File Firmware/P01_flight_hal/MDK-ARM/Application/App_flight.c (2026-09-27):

#include "App_flight.h"

Gyro_Accel_Struct gyro_accel_data = { 0 };
Euler_Struct euler_angle = { 0 }; 
Gyro_Struct last_gyro = { 0 };

float gyro_z_sum = 0; 

// Pitch angle 
PID_Struct pitch_pid = { .kp = -7.00, .ki = 0.00, .kd = 0.00};
PID_Struct gyro_y_pid = { .kp = 3.00, .ki = 0.00, .kd = 0.50};

// Row angle
PID_Struct row_pid = { .kp = -7.00, .ki = 0.00, .kd = 0.00};
PID_Struct gyro_x_pid = { .kp = 3.00, .ki = 0.00, .kd = 0.50};

// Yaw angle
PID_Struct yaw_pid = { .kp = -3.00, .ki = 0.00, .kd = 0.00};
PID_Struct gyro_z_pid = { .kp = -5.00, .ki = 0.00, .kd = 0.00};

extern Remote_data remote_data; 
extern Flight_State flight_state;
extern TaskHandle_t com_task_handle;

extern uint16_t fix_height;

PID_Struct height_pid = { .kp = -0.60, .ki = 0.00, .kd = -0.20};

Motor_Struct left_top_motor = { .tim = &htim3, .channel = TIM_CHANNEL_1, .speed = 0 };
Motor_Struct left_bottom_motor = { .tim = &htim4, .channel = TIM_CHANNEL_4, .speed = 0 };
Motor_Struct right_top_motor = { .tim = &htim2, .channel = TIM_CHANNEL_2, .speed = 0 };
Motor_Struct right_bottom_motor = { .tim = &htim1, .channel = TIM_CHANNEL_3, .speed = 0 };


/**
 * @brief Initialize MPU6050 and start motors
 */
void App_flight_init(void)
{
    Int_MPU6050_Init();

    Init_motor_start(&left_top_motor);
    Init_motor_start(&left_bottom_motor);
    Init_motor_start(&right_top_motor);
    Init_motor_start(&right_bottom_motor);

    Int_VL53L1X_Init(); 
}

/**
 * @brief Calculate Euler angle based on gyro data
 */
void App_flight_get_euler_angle(void)
{
    Int_MPU6050_Get_Data(&gyro_accel_data);

    // Apply low pass filter for gyro data (more stable)
    gyro_accel_data.gyro.gyro_x = Common_Filter_LowPass(gyro_accel_data.gyro.gyro_x, last_gyro.gyro_x);
    gyro_accel_data.gyro.gyro_y = Common_Filter_LowPass(gyro_accel_data.gyro.gyro_y, last_gyro.gyro_y);
    gyro_accel_data.gyro.gyro_z = Common_Filter_LowPass(gyro_accel_data.gyro.gyro_z, last_gyro.gyro_z);

    last_gyro.gyro_x = gyro_accel_data.gyro.gyro_x; 
    last_gyro.gyro_y = gyro_accel_data.gyro.gyro_y; 
    last_gyro.gyro_z = gyro_accel_data.gyro.gyro_z; 

    // Apply Kalman filter for accel data (very unstable)
    gyro_accel_data.accel.accel_x = Common_Filter_KalmanFilter(&kfs[0], gyro_accel_data.accel.accel_x);
    gyro_accel_data.accel.accel_y = Common_Filter_KalmanFilter(&kfs[1], gyro_accel_data.accel.accel_y);
    gyro_accel_data.accel.accel_z = Common_Filter_KalmanFilter(&kfs[2], gyro_accel_data.accel.accel_z);

    // Attitude Estimation => Complementary Filter (Angular velocity integration + Acceleration estimation)
    // euler_angle.pitch = atan2(gyro_accel_data.accel.accel_x * 1.0, gyro_accel_data.accel.accel_z) / 3.14159 * 180;
    // euler_angle.roll = atan2(gyro_accel_data.accel.accel_y * 1.0, gyro_accel_data.accel.accel_z) / 3.14159 * 180;

    // gyro_z_sum += (gyro_accel_data.gyro.gyro_z * 2000.0 / 32768.0) * 0.006;
    // euler_angle.yaw = gyro_z_sum; 

    Common_IMU_GetEulerAngle(&gyro_accel_data, &euler_angle, 0.006);
}

/**
 * @brief Calculate PID values based on Euler angles
 */
void App_flight_pid_process(void)
{
    // Pitch angle 
    pitch_pid.desire = (remote_data.pit - 500) / 50.0;
    pitch_pid.measure = euler_angle.pitch; 
    
    gyro_y_pid.measure = gyro_accel_data.gyro.gyro_y * 2000.0 / 32768.0;

    Com_PID_Calc_Chain(&pitch_pid, &gyro_y_pid); 

    // Row angle
    row_pid.desire = (remote_data.rol - 500) / 50.0;
    row_pid.measure = euler_angle.roll; 

    gyro_x_pid.measure = gyro_accel_data.gyro.gyro_x * 2000.0 / 32768.0;

    Com_PID_Calc_Chain(&row_pid, &gyro_x_pid);

    // Yaw angle
    yaw_pid.desire = (remote_data.yaw - 500) / 50.0;
    yaw_pid.measure = euler_angle.yaw; 

    gyro_z_pid.measure = gyro_accel_data.gyro.gyro_z * 2000.0 / 32768.0;

    Com_PID_Calc_Chain(&yaw_pid, &gyro_z_pid);
}

/**
 * @brief Control motors based on PID values 
 */
void App_flight_control_motor(void)
{
    switch (flight_state)
    {
    case IDLE:
        left_top_motor.speed = 0;
        left_bottom_motor.speed = 0;
        right_top_motor.speed = 0;
        right_bottom_motor.speed = 0;
        break;

    case NORMAL:
        left_top_motor.speed = remote_data.thr + gyro_y_pid.output - gyro_x_pid.output + gyro_z_pid.output;
        left_bottom_motor.speed = remote_data.thr - gyro_y_pid.output - gyro_x_pid.output - gyro_z_pid.output;
        right_top_motor.speed = remote_data.thr + gyro_y_pid.output + gyro_x_pid.output - gyro_z_pid.output;
        right_bottom_motor.speed = remote_data.thr - gyro_y_pid.output + gyro_x_pid.output + gyro_z_pid.output;
        break;

    case FIX_HEIGHT:
        left_top_motor.speed = remote_data.thr + gyro_y_pid.output - gyro_x_pid.output + gyro_z_pid.output + height_pid.output;
        left_bottom_motor.speed = remote_data.thr - gyro_y_pid.output - gyro_x_pid.output - gyro_z_pid.output + height_pid.output;
        right_top_motor.speed = remote_data.thr + gyro_y_pid.output + gyro_x_pid.output - gyro_z_pid.output + height_pid.output;
        right_bottom_motor.speed = remote_data.thr - gyro_y_pid.output + gyro_x_pid.output + gyro_z_pid.output + height_pid.output;
        break;

    case FAIL: 
        left_top_motor.speed -= 2;
        left_bottom_motor.speed -= 2;
        right_top_motor.speed -= 2;
        right_bottom_motor.speed -= 2;

        if (left_top_motor.speed <= 0 &&
            left_bottom_motor.speed <= 0 &&
            right_top_motor.speed <= 0 &&
            right_bottom_motor.speed <= 0)
        {
            xTaskNotifyGive(com_task_handle);
        }
        break; 

    default:
        break;
    }

    left_top_motor.speed = Com_Limit(left_top_motor.speed, 600, 0);
    left_bottom_motor.speed = Com_Limit(left_bottom_motor.speed, 600, 0);
    right_top_motor.speed = Com_Limit(right_top_motor.speed, 600, 0);
    right_bottom_motor.speed = Com_Limit(right_bottom_motor.speed, 600, 0);

    if (remote_data.thr < 50)
    {
        left_top_motor.speed = 0;
        left_bottom_motor.speed = 0;
        right_top_motor.speed = 0;
        right_bottom_motor.speed = 0;
    }

    Init_motor_set_speed(&left_top_motor);
    Init_motor_set_speed(&left_bottom_motor);
    Init_motor_set_speed(&right_top_motor);
    Init_motor_set_speed(&right_bottom_motor);
}

/**
 * @brief Calculate PID values for fix height mode
 */
void App_flight_fix_height_pid_process(void)
{
    height_pid.desire = fix_height; 
    height_pid.measure = Int_VL53L1X_Get_Distance();

    Com_PID_Calc(&height_pid);
}

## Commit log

2026-07-07 Wireless Com Task Completed
    [BOM_Flight_2026-07-06.xlsx, BOM_Remote_2026-07-06.xlsx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]
2026-07-08 Button (key) task completed
    Added key interface for reading button short/long press
    [App_freeRTOS_Task.c, Int_SI24R1.c, Int_SI24R1.h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]
2026-07-19 Completed Attitude Estimation with complementary filter
2026-07-28 Finish basic PID motor control
2026-07-29 PID tuning completed
2026-08-02 Fix height feature implemented
    [App_flight.c, App_freeRTOS_Task.c, Int_VL53L1X.c]
2026-09-27 Fix naming and minor bugs
    [App_flight.c, App_freeRTOS_Task.c]
